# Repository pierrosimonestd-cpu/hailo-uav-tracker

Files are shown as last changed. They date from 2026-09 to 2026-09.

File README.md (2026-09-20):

# hailo-uav-tracker

**Real-time UAV detection and pan/tilt tracking on a Raspberry Pi 5 with a 13 TOPS Hailo-8L NPU.**





A camera on a two-axis turret finds a drone in the sky, decides which one to
follow, and keeps it centred while it moves. Detection runs on the NPU; the
tracker and a latency-compensating controller run on the Pi's CPU; an ESP32
drives the servos and holds a failsafe that does not depend on the Pi being
alive.

Accuracy is reported on the public [DUT Anti-UAV](https://github.com/wangdongdut/DUT-Anti-UAV)
benchmark (IEEE T-ITS 2022) under the COCO protocol. Pointing performance is
reported from a closed-loop simulation, clearly labelled as such. Every number
in this repository is produced by a script in `benchmarks/` and written to a
JSON file you can inspect.

---

## What is interesting here

Most edge-vision projects stop at "the model runs at N FPS". The question this
one is built around is different:

> **What does inference latency cost you in degrees of pointing error?**

It turns out that is the *only* question that matters for a tracking turret, and
it has a clean answer. Inference time enters the control loop as dead time. Dead
time caps the achievable loop bandwidth at roughly

$$\omega_c \approx \frac{0.8}{T_d + \tau}$$

which for this hardware is under 1 Hz — while the servos themselves could slew at
600 °/s. **The loop is latency-limited, not actuator-limited.** That is what the
accelerator buys, and it is measured on the real board: 153.6 ms of inference on
the Pi's CPU becomes 13.6 ms on the Hailo-8L, and steady-state pointing error
falls from 1.41° to 0.65°.

<!-- BEGIN GENERATED: readme-latency -->
| Sense-to-act latency | RMS pointing error |  |
| --- | --- | --- |
| 10 ms | **0.68°** | an accelerator with headroom to spare |
| 45 ms | **0.83°** | the budget `configs/rpi5_hailo8l.yaml` assumes |
| 120 ms | **1.21°** | a pipeline four times slower |
| 300 ms | **2.77°** | a pipeline near the edge of usable |
<!-- END GENERATED: readme-latency -->

Along the way, three things turned out to be more subtle than expected, and each
is written up with the wrong answers included:

- **Velocity feed-forward has two plausible formulations, and both are unstable.**
  Reconstructing the target's absolute rate from "apparent rate plus my own rate"
  is positive feedback with loop gain equal to the feed-forward gain.
  Reconstructing it from the commanded *angle* looks safe but puts a positive
  real pole at `1/τ_servo` into the loop. What works is reconstructing through a
  forward model of the actuator. [Write-up →](docs/control-design.md#5-velocity-feed-forward-and-two-ways-to-get-it-wrong)
- **The aim-time lead is the actuator's lag, not another detection latency.**
  Getting this wrong is invisible: it is correct at one particular frame rate.
  It produced a spurious minimum in the latency curve that looked like a real
  result. [Write-up →](docs/control-design.md#6-aim-time-a-subtle-but-expensive-detail)
- **The obvious serial protocol fails silently and permanently.** Two raw bytes
  per command means one dropped byte swaps pan and tilt for as long as the link
  stays up, and neither end can tell. [Write-up →](docs/hardware.md#why-not-two-raw-bytes)

---

## Results

### Detection — DUT Anti-UAV test split, COCO protocol

<!-- BEGIN GENERATED: detection -->
| Model | Backend | AP | AP50 | AP75 | AP_S | AP_M | AP_L | Images |
| ---: | ---: | ---: | ---: | ---: | ---: | ---: | ---: | ---: |
| `yolov8n-fp32-onnx` | onnx:cpu | 0.556 | 0.894 | 0.585 | 0.418 | 0.578 | 0.717 | 2200 |
| `yolov8n-fp32-pytorch` | ultralytics:cpu | 0.543 | 0.886 | 0.574 | 0.395 | 0.567 | 0.713 | 2200 |
| `yolov8n-int8-onnx` | onnx:cpu | 0.518 | 0.875 | 0.522 | 0.358 | 0.536 | 0.709 | 2200 |
| `yolov8n-negatives` | ultralytics:cpu | 0.503 | 0.865 | 0.514 | 0.356 | 0.559 | 0.657 | 2200 |
<!-- END GENERATED: detection -->

Read `AP_S` first: **52% of the objects in this dataset are smaller than 32×32
pixels**, and the median object covers under one tenth of one percent of the
frame. An aggregate AP can look respectable while the model has stopped seeing
distant targets, which are the ones worth detecting early.

### Latency

<!-- BEGIN GENERATED: latency -->
| Model | Host | Backend | Inference (ms) | End to end (ms) | p95 | p99 | FPS |
| ---: | ---: | ---: | ---: | ---: | ---: | ---: | ---: |
| `yolov8n-fp32-onnx-rpi5cpu` | Pi 5 CPU | onnx:cpu | 153.6 | 153.9 | 180.9 | 183.0 | 6.5 |
| `yolov8n-int8-onnx-rpi5cpu` | Pi 5 CPU | onnx:cpu | 75.0 | 75.3 | 93.6 | 96.0 | 13.3 |
| `yolov8n-fp32-onnx` | x86 desktop | onnx:cpu | 39.8 | 40.1 | 45.2 | 50.4 | 24.9 |
| `yolov8s-int8-hailo8l` | Pi 5 + Hailo-8L | hailo8l | 19.9 | 20.2 | 22.8 | 23.0 | 49.5 |
| `yolov8n-int8-hailo8l` | Pi 5 + Hailo-8L | hailo8l | 13.6 | 13.8 | 14.0 | 14.2 | 72.7 |
<!-- END GENERATED: latency -->

### Tracking — DUT Anti-UAV sequences

<!-- BEGIN GENERATED: tracking -->
| Model | Sequences | Frames | Success AUC | Success@0.5 | P@20px | Recall | Re-acquisitions |
| ---: | ---: | ---: | ---: | ---: | ---: | ---: | ---: |
| `yolov8n-fp32-pytorch` | 20 | 24,804 | 0.593 | 0.748 | 0.790 | 0.816 | 193 |
<!-- END GENERATED: tracking -->

Detect-and-track with no ground-truth initialisation, so this is a strictly
harder task than the single-object-tracking baselines published with the
dataset and is not compared against them. *Recall* keeps the rest honest: a
tracker can post a good success curve while answering on a third of the frames.

### Bird discrimination — the weakest result, and what fixing it costs

DUT Anti-UAV contains no birds, so a model trained on it alone has never been
told that a bird is not a drone. Measured against 593 bird photographs from
Open Images V7, with aircraft classes excluded:

<!-- BEGIN GENERATED: hard-negatives -->
| Model | Bird images | Threshold | False-positive rate | Threshold for 1% |
| ---: | ---: | ---: | ---: | ---: |
| `yolov8n-fp32-pytorch` | 593 | 0.35 | 23.44% | 0.9 |
| `yolov8n-negatives` | 593 | 0.35 | 7.08% | 0.7 |
<!-- END GENERATED: hard-negatives -->

**Close to one bird image in four triggers a UAV detection** on the baseline
model, which has never been shown a bird and told it is not a drone. Adding 600
bird photographs to training as background images and fine-tuning for four
epochs takes that to 7%.

That second number means nothing on its own — raising the confidence threshold
suppresses birds too, for free. And the fine-tuned model is *behind* on the
drone benchmark: AP 0.543 to 0.503. The obvious reading is that it just became
timid.

It did not. Compared at matched bird false-positive rates, it finds
substantially more drones at every operating point:

<!-- BEGIN GENERATED: negatives-tradeoff -->
| Target bird FP | Baseline thr / actual | Recall | With negatives thr / actual | Recall | &Delta; |
| ---: | ---: | ---: | ---: | ---: | ---: |
| 10.0% | 0.60 / 9.9% | 0.713 | 0.25 / 9.6% | **0.821** | +15% |
| 6.0% | 0.70 / 5.7% | 0.600 | 0.40 / 5.2% | **0.783** | +31% |
| 3.5% | 0.80 / 2.2% | 0.360 | 0.60 / 2.0% | **0.661** | +83% |
| 2.0% | 0.90 / 0.2% | 0.033 | 0.70 / 0.8% | **0.485** | +1392% &dagger; |

&dagger; the two models' actual bird rates differ by more than 1.5x here, so this row is not a matched comparison and its relative gain is overstated.
<!-- END GENERATED: negatives-tradeoff -->

The baseline needs confidence 0.70 to get birds to 5.7%, and there it has lost
40% of the drones. The fine-tuned model reaches a lower bird rate at 0.40, where
it still sees 78%. Its AP is lower because AP integrates the whole
precision-recall curve including the low-confidence tail no turret operates in —
the right summary for a detector in general, the wrong one for this decision.

Both checkpoints are kept, because which to deploy depends on whether false
alarms or missed drones cost more, and that is not a benchmark question.
[Method, caveats and the disjoint-split check](docs/benchmarks.md#fixing-it-birds-as-training-background).

### Predictions

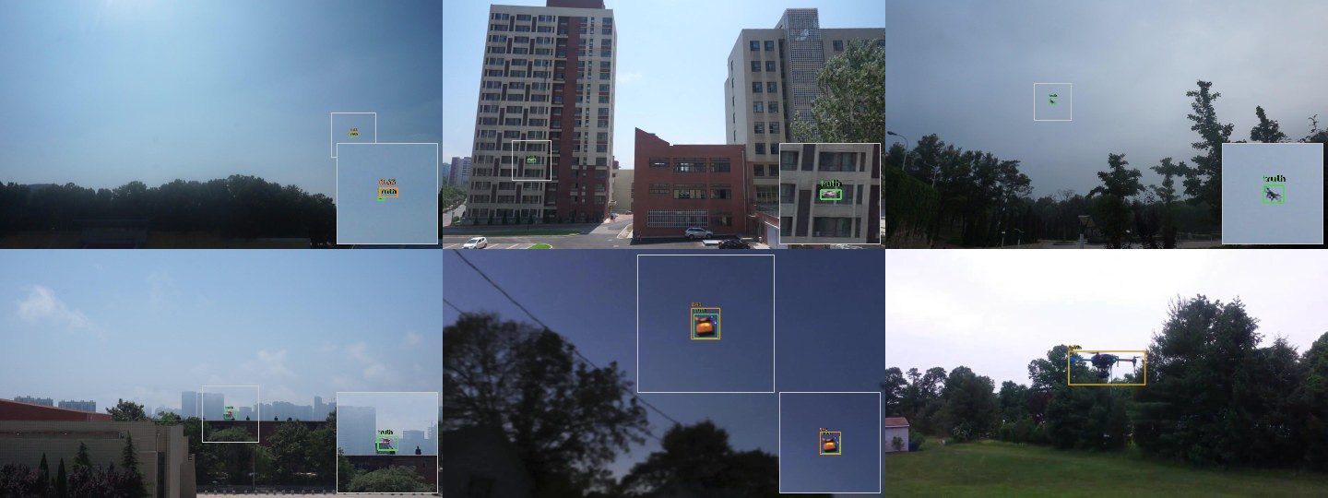
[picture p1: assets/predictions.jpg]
Predictions against ground truth


Six test images spanning the object-size range, smallest first. Green is ground
truth, orange is the model. Where the target is too small to see at this scale
the outlined region is magnified into the corner — which is itself the point:
most of this benchmark looks like the top-left cell, not the bottom-right one.

### Velocity feed-forward — closed-loop simulation

<!-- BEGIN GENERATED: readme-feedforward -->
| Target angular rate | PID only | PID + feed-forward |  |
| ---: | ---: | ---: | ---: |
| 4.7 °/s | 1.02° | **0.34°** | 67% lower |
| 14.1 °/s | 2.89° | **0.83°** | 71% lower |
| 28.3 °/s | 5.48° | **2.86°** | 48% lower |
<!-- END GENERATED: readme-feedforward -->

Full tables, methodology and the reproduction commands: **[docs/benchmarks.md](docs/benchmarks.md)**

---

## Quick start

### On a laptop, no hardware needed

```bash
git clone https://github.com/pierrosimonestd-cpu/hailo-uav-tracker
cd hailo-uav-tracker
pip install -e ".[dev,onnx,bench]"

pytest tests                                    # the whole library, no NPU required
python benchmarks/bench_control.py --study all  # reproduce the pointing tables
uavtrack simulate --trajectory crossing --latency-ms 45
```

### On the Raspberry Pi

```bash
sudo apt install -y hailo-all python3-picamera2
pip install -e .                                # NumPy, OpenCV, PyYAML, pyserial

uavtrack check --config configs/rpi5_hailo8l.yaml
uavtrack run   --config configs/rpi5_hailo8l.yaml --display
```

Full deployment guide, including compiling the model:
**[docs/hailo-deployment.md](docs/hailo-deployment.md)**

### Train your own detector

```bash
python tools/fetch_dut_antiuav.py --out data/dut_antiuav   # 10,000 annotated images
python tools/prepare_dataset.py   --root data/dut_antiuav  # VOC → YOLO + COCO
python tools/train_uav.py --epochs 20 --cache ram
python tools/export_onnx.py --weights runs/train/uav_yolov8n/weights/best.pt
bash tools/compile_hailo.sh models/uav_yolov8n_640.onnx    # needs the Hailo DFC
```

---

## How it works

```
┌────────────┐   BGR frame    ┌──────────────┐   detections   ┌─────────────┐
│  Camera    │───────────────▶│   Detector   │───────────────▶│   Tracker   │
│ Picamera2  │  1280×720@30   │  Hailo-8L    │  boxes+scores  │  ByteTrack  │
└────────────┘                │  YOLOv8n     │                │  + Kalman   │
      ▲                       └──────────────┘                └─────────────┘
      │                                                              │
      │ camera is rigidly mounted on the turret                      │
      │                                                              ▼
┌────────────┐   pan/tilt    ┌──────────────┐   target px    ┌─────────────┐
│  Servos    │◀──────────────│  ESP32       │◀───────────────│  Controller │
│  MG90S ×2  │     PWM       │ framed UART  │  pan/tilt deg  │  PID + FF   │
└────────────┘               └──────────────┘                └─────────────┘
```

| Stage | Runs on | Why |
|---|---|---|
| Detection + NMS | **Hailo-8L NPU** | 13 TOPS; NMS is compiled into the HEF so the CPU never sees raw head tensors |
| Tracking + control | Pi 5 CPU | Microseconds, NumPy only |
| Servo drive + failsafe | ESP32 | Hard-real-time PWM, and a failsafe independent of the Pi |

**Design notes worth reading:** [architecture.md](docs/architecture.md) ·
[control-design.md](docs/control-design.md) · [hardware.md](docs/hardware.md) ·
[dataset.md](docs/dataset.md)

### A few decisions and their reasons

**The Raspberry Pi install has no PyTorch.** Runtime dependencies are NumPy,
OpenCV, PyYAML and pyserial. The YOLO decode path is written in NumPy for this
reason. Training and benchmarking live in optional extras.

**One `Detection` type, three backends.** Hailo, ONNX Runtime and PyTorch all
return identical objects in original-frame pixels. The accuracy benchmark runs
the *same code path* the live pipeline runs, so it measures the system rather
than a benchmark-only wrapper — and the tests run on machines with no NPU.

**Timestamps come from capture, not from a nominal frame rate.** Inference time
on a shared NPU varies; a loop that assumes fixed `dt` accumulates a timing error
the Kalman filter cannot see.

**The failsafe is in the firmware.** If the Pi crashes, Python cannot clean up —
that is what crashing means. The ESP32 cuts the effector and detaches the servos
after 500 ms of silence, and the Pi sends heartbeats so silence is always
deliberate.

**Config typos are fatal.** `conf_treshold: 0.5` raises at startup instead of
being silently ignored.

---

## Repository layout

```
src/uavtrack/      detect/ · track/ · control/ · io/ · data/   the library
firmware/          ESP32 pan/tilt controller, framed protocol
hardware/cad/      printable STL/3MF plus Creo sources
benchmarks/        detection, tracking, latency, hard negatives, control
tools/             dataset fetch/prepare, train, export, quantise, Hailo compile
configs/           Pi + Hailo, and a desktop ONNX config
docs/              architecture, control design, benchmarks, hardware, dataset
tests/             274 tests, plus a C++ conformance test for the firmware
```

## Testing

```bash
pytest tests                       # runs anywhere; no NPU, no PyTorch, no turret
```

274 tests, 86% line coverage. The uncovered remainder is almost entirely the
three device-backed detection backends — Hailo needs an NPU, Ultralytics needs
PyTorch and a checkpoint — which is why everything downstream of them is written
against one `Detection` type that a stub can produce.

Some of those tests exist to keep the documentation honest rather than the code
correct: one re-derives every figure quoted in
[control-design.md](docs/control-design.md) from the measured JSON, another
fails on a broken link or a referenced script that does not exist, and a third
imports the whole library in a subprocess with PyTorch, ONNX Runtime, HailoRT
and SciPy blocked, so the claim about the Raspberry Pi install is enforced
rather than asserted.

CI additionally compiles the **actual firmware header** with a host C++ compiler
and runs the same protocol vectors and adversarial byte streams against it, so
the ESP32 and Python implementations cannot drift apart silently. It also builds
the firmware with `arduino-cli`, and fails if `docs/benchmarks.md` no longer
matches the JSON files in `benchmarks/results/`.

The tests that earn their keep are the ones pinning down specific failures: a
byte dropped on the serial link, a frame missed by the detector, an integrator
charging against a travel limit. Two real bugs found this way are documented in
[control-design.md](docs/control-design.md) §6 and [dataset.md](docs/dataset.md).

## What this does not do

Stated plainly, because a project's honesty is in what it admits rather than
what it claims.

**The accelerator numbers are not this project's detector.** The Hailo-8L
latency in the table above is measured — on a real Pi 5 with the AI HAT+,
`hailortcli` reporting `Device Architecture: HAILO8L`, firmware 4.23.0, through
this repository's own `HailoDetector` — but the compiled model is Hailo's
**COCO-trained yolov8n** from their Model Zoo, not the UAV detector trained
here. Compiling a `.hef` needs the Hailo Dataflow Compiler, which is x86_64
Linux only and behind a Developer Zone account, so the UAV weights have not
been through it.

The consequence is exact: the **latency is representative** — same
architecture, same 640×640 input, same device, same board — and **no detection
accuracy in this README was measured on the accelerator**. Run
`tools/compile_hailo.sh` on an x86 Linux box, copy the HEF to the Pi, and
`benchmarks/bench_latency.py` plus `benchmarks/eval_detection.py` will fill in
the rows that are still missing.

**The pointing results are simulation.** A rate-limited servo model with
transport delay, documented in [`plant.py`](src/uavtrack/control/plant.py). It
does not model backlash, stiction, boresight misalignment or a flexing 3D-printed
yoke — [control-design.md](docs/control-design.md) §9 lists the omissions. It is
how you decide what to take to the hardware, not a substitute for doing so.

**The INT8 study is a proxy.** ONNX Runtime static quantisation shares the
mechanisms that matter with the Hailo quantiser, but it is not that quantiser.

**Bird discrimination is improved, not solved.** The fine-tuned checkpoint still
fires on 7% of bird images, and the training and evaluation negatives are both
Open Images photographs — perched birds, close-ups, birds indoors — not birds in
flight against sky at range, which is the case that matters. The measurement is
a proxy, better than none and not the real thing. Four CPU epochs is also a small
budget for 600 new images; training with them included from the start would
likely beat both checkpoints rather than trading against one.

**The resize-kernel gain does not apply to the shipped configuration.** The
`INTER_AREA` preprocessing is worth about two points of `AP_small` on the
benchmark, but all of that comes from its 1920×1080 images. At the 1280×720 the
Pi config captures, the downscale to 640 is exactly 2:1, where OpenCV's bilinear
filter matches area-averaging to within one intensity level and the gain is
zero. Capturing
at 1080p might recover it; that has not been measured on hardware.
[Details](docs/benchmarks.md#the-resize-kernel-and-a-correctness-proof).

**Monocular, so no range.** Everything is angular. Two targets on the same
bearing at different distances are indistinguishable, which is simply true of
one camera.

**One target at a time.** The tracker follows several; the turret points at one,
chosen with hysteresis and a dwell time. No multi-target scheduling.

**Visible light only.** No thermal channel, so no night capability and a hard
time against a bright overcast sky.

**The servo model is unidentified.** `tau_s` and `delay_s` in
[`plant.py`](src/uavtrack/control/plant.py) are placeholders; the slew rate is
the MG90S datasheet figure. Until you identify your own, keep
`feedforward_gain` at 0.9 rather than 1.0 — the feed-forward is only as good as
that model.

## Credits and licence

MIT, see [LICENSE](LICENSE).

- **DUT Anti-UAV** — Zhao, Zhang, Li, Wang, *Vision-based Anti-UAV Detection and
  Tracking*, IEEE T-ITS 2022. [Dataset](https://github.com/wangdongdut/DUT-Anti-UAV)
- **ByteTrack** — Zhang et al., ECCV 2022,
  [arXiv:2110.06864](https://arxiv.org/abs/2110.06864). The association strategy;
  this is an independent implementation, not a port.
- **Ultralytics YOLOv8** — training and export.
- **Hailo** — HailoRT, the Dataflow Compiler and the published Model Zoo figures
  quoted in [benchmarks.md](docs/benchmarks.md) §4.
- **Open Images V7** — bird images for the hard-negative benchmark.

Hailo throughput figures quoted in this repository are Hailo's own published
COCO measurements on an Intel host, attributed as such, and are not measurements
from this project.

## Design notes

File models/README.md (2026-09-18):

# Model artifacts

This directory is where the build products land. None of them are committed —
they are derived files, and a repository that carries 25 MB of weights per
experiment stops being clonable.

| File | Produced by | Used by |
|---|---|---|
| `uav_yolov8n_640.onnx` | `tools/export_onnx.py` | ONNX Runtime backend; input to the Hailo compiler |
| `uav_yolov8n_640.int8.onnx` | `tools/quantize_onnx.py` | The INT8 accuracy study |
| `calibration.npy` | `tools/make_calibration_set.py` | The Hailo optimiser |
| `uav_yolov8n_640.har` | `tools/compile_hailo.sh` (parse step) | Intermediate; inspect with `hailo profiler` |
| `uav_yolov8n_640.hef` | `tools/compile_hailo.sh` (compile step) | What actually runs on the Pi |

## Getting a model

Train one:

```bash
python tools/fetch_dut_antiuav.py --out data/dut_antiuav
python tools/prepare_dataset.py   --root data/dut_antiuav
python tools/train_uav.py --epochs 20 --cache ram
python tools/export_onnx.py --weights runs/train/uav_yolov8n/weights/best.pt
```

Then, on an x86_64 machine with the Hailo Dataflow Compiler:

```bash
python tools/make_calibration_set.py --out models/calibration.npy
bash tools/compile_hailo.sh models/uav_yolov8n_640.onnx models/calibration.npy
```

See [docs/hailo-deployment.md](../docs/hailo-deployment.md) for the parts of
that flow that will bite you.

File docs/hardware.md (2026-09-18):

# Hardware

A two-axis pan/tilt turret carrying a camera, driven by an ESP32, commanded by a
Raspberry Pi 5 with a Hailo-8L NPU.

## Bill of materials

| Part | Notes |
|---|---|
| Raspberry Pi 5, 4 GB or 8 GB | 8 GB only helps if you also train on it, which you should not |
| Raspberry Pi AI HAT+ 13 TOPS (Hailo-8L) | The 26 TOPS Hailo-8 variant works unchanged; set `HW_ARCH=hailo8` when compiling |
| Raspberry Pi Camera Module 3 | 66° horizontal FOV. Any camera works — **measure the FOV** |
| ESP32 devkit (e.g. DOIT DevKit v1) | Any ESP32 with USB serial |
| 2 × MG90S metal-gear servo | Plastic-gear SG90s strip under the side loads from a camera mount |
| 5 V 2 A+ supply for the servos | **Separate from the Pi.** See below |
| Logic-level MOSFET module or 3.3 V relay | Drives the effector output |
| 608ZZ bearing | Takes the radial load off the pan servo's output shaft |
| M3 hardware, USB-C cable | |

Printed parts are in [`../hardware/cad`](../hardware/cad) — STL and 3MF for
printing, Creo sources under `creo/`.

| File | Part |
|---|---|
| `base_plate.stl` | Fixed base, pan servo mount |
| `base_rpi5_tray.stl` | Pi 5 + AI HAT+ tray |
| `yoke_pan.stl` | Rotating yoke |
| `tilt_arm.stl` | Tilt arm |
| `camera_mount_v2.stl` | Camera mount (v2; v1 kept for reference) |
| `bearing_holder.stl` | 608ZZ seat |
| `yoke_mg90s_fit_test.stl` | Print this first — checks the servo pocket fit |

Print `yoke_mg90s_fit_test.stl` before committing to a four-hour print. Servo
body tolerances vary between suppliers, and a pocket 0.3 mm undersized means
either a broken part or a servo you cannot remove.

The Creo sources under `hardware/cad/creo/` keep the native `.prt.N` versioning,
where the **highest** `N` is the current revision -- `base.prt.6` supersedes
`base.prt.5`. Earlier revisions are kept because they are the design history;
only the STL and 3MF exports are what you print.

The part names are Italian, because that is what they were modelled as, and
renaming a Creo part breaks retrieval by name. So they are translated rather
than renamed:

| Creo part | Literally |
|---|---|
| `base.prt` | "base" |
| `base_rpi.prt` | "Raspberry Pi base" |
| `u_torretta.prt` | "turret" |
| `attacco_camera.prt` | "camera attachment" |
| `attacco_cuscinetto_rivisto.prt` | "revised bearing seat" |
| `prt0001.prt`, `prt0002.prt` | nothing -- Creo's default name for a part nobody renamed |

Which STL each one exports to was never recorded, so it is not claimed here.
Open the part if you need to know; the printable geometry is the STL either way.

## Power — read this part

**Do not power the servos from the Pi or from the ESP32.** MG90S stall current
is around 700 mA each, with startup transients well above that. An ESP32's
regulator supplies a few hundred milliamps, so the board browns out and resets
the instant both servos move together. The symptom is a turret that works
perfectly until it has to track something.

```
5 V 2 A+ supply ──┬── servo V+ (red)
                  └── (do NOT connect to the ESP32 5 V pin)

        GND ──────┬── servo GND (brown/black)
                  ├── ESP32 GND
                  └── MOSFET / relay module GND        ← all grounds common
```

The common ground is not optional. Without it the PWM signal has no reference
and the servos jitter or ignore commands entirely.

A 470–1000 µF electrolytic across the servo supply, physically close to the
servos, absorbs the switching transients. Cheap, and it removes a whole class of
intermittent faults.

## Wiring

| Signal | ESP32 pin | Goes to |
|---|---|---|
| Pan servo PWM | GPIO 13 | Servo signal (orange/yellow) |
| Tilt servo PWM | GPIO 12 | Servo signal |
| Effector | GPIO 21 | MOSFET gate or relay input |
| Serial | USB-C | Raspberry Pi USB port |

Pin assignments are at the top of
[`esp32_pantilt.ino`](../firmware/esp32_pantilt/esp32_pantilt.ino).

The effector pin **cannot drive a load directly** — an ESP32 GPIO supplies 3.3 V
at a few tens of milliamps. Use a logic-level MOSFET (IRLZ44N or similar) or a
relay module rated for 3.3 V logic.

### Servo pulse range

The firmware attaches the servos with a 500–2400 µs pulse range rather than the
1000–2000 µs Arduino default. MG90S servos use the wider range; clipping it
throws away roughly a third of the mechanical travel, which shows up as a turret
that mysteriously cannot reach the edges of its own field of regard.

## Mechanical limits

Configured in both `configs/rpi5_hailo8l.yaml` and the firmware, deliberately:

| Axis | Range | Why |
|---|---|---|
| Pan | 0–180° | Full servo travel |
| Tilt | 20–160° | The camera mount fouls the base below 20° |

**Check these against your own build before powering on.** Both ends enforce
them so a bug on the Pi cannot drive the mechanism into itself, but neither end
knows your print tolerances.

## Firmware

```bash
arduino-cli config init
arduino-cli config set board_manager.additional_urls \
  https://raw.githubusercontent.com/espressif/arduino-esp32/gh-pages/package_esp32_index.json
arduino-cli core update-index
arduino-cli core install esp32:esp32
arduino-cli lib install ESP32Servo

arduino-cli compile --fqbn esp32:esp32:esp32doit-devkit-v1 firmware/esp32_pantilt
arduino-cli upload -p /dev/ttyUSB0 --fqbn esp32:esp32:esp32doit-devkit-v1 firmware/esp32_pantilt
```

If upload fails at `Connecting...`, hold the BOOT button until it starts.

### What the firmware guarantees

The Pi does the thinking; the firmware's entire job is to be the part that stays
safe when the thinking stops.

- **Failsafe.** No valid frame for 500 ms and the effector is cut and the servos
  are *detached* — PWM stops, so they go limp rather than straining against
  whatever they are pressed into. The Pi sends heartbeats to prove it is alive,
  so silence is always deliberate.
- **Starts inert.** The turret does not move on power-up until the host has
  spoken to it. A power cycle cannot make it move on its own.
- **Framed commands.** Sync word, length, CRC-8. A corrupt frame is counted and
  dropped, never acted on.
- **Independent rate limiting.** Commands are slew-limited in the firmware as
  well as on the Pi, so a bad command cannot ask for a step big enough to brown
  out the supply.
- **Telemetry.** A `STATUS` frame every 200 ms reporting the last sequence
  number, dropped frames and CRC errors — so link quality is observable rather
  than guessed at.

### Why not two raw bytes

The obvious protocol is to write pan and tilt as two bytes and have the firmware
read them whenever two are available. It has a failure mode that is silent and
permanent: drop one byte anywhere and every subsequent pair is read off by one,
so pan is interpreted as tilt for as long as the link stays up. Neither end can
tell.

Measured on the framed protocol with 1% of bytes randomly dropped: **173 of 200
frames recovered, and zero frames delivered with wrong content**
(`tests/test_protocol.py`). Frames are lost, never misread. That is the property
worth having, and it costs seven bytes of overhead per command.

The full frame layout is in
[`protocol.py`](../src/uavtrack/io/protocol.py), and
[`protocol.h`](../firmware/esp32_pantilt/protocol.h) must stay byte-identical —
`tests/test_protocol.py` pins the CRC vectors both sides have to reproduce.

## Assembly notes

1. Print and test-fit `yoke_mg90s_fit_test.stl` first.
2. Centre both servos at 90° **before** attaching the horns, or the mechanical
   range will be offset from the commanded range and the limits will be wrong.
3. Seat the 608ZZ bearing in `bearing_holder.stl` — it carries the radial load
   the pan servo's output shaft should not.
4. Route the camera ribbon with slack through the full pan range. It is the
   first thing to fail.
5. Power the servo supply and the Pi separately; join grounds.
6. Upload the firmware and verify with `uavtrack check` before mounting the
   camera.

## Calibrating the field of view

`horizontal_fov_deg` sets the pixel-to-angle gain for the whole control loop.
Getting it wrong is indistinguishable from mistuning every gain at once.

Measure it: place a target of known width `W` at a known distance `D`,
perpendicular to the optical axis, and note the pixel width `p` it occupies in a
full-frame capture.

$$\text{HFOV} = 2\arctan\left(\frac{W_\text{frame}}{2D}\right), \qquad W_\text{frame} = W\cdot\frac{W_\text{image px}}{p}$$

Put the result in your config. Do not trust the marketing figure — it is quoted
for the full sensor, and most capture modes crop.

---

**See also:** [control-design.md](control-design.md) ·
[hailo-deployment.md](hailo-deployment.md)

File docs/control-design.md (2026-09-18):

# Control design

How the turret decides where to point, why it is built this way, and what each
decision is worth in measured degrees.

Everything here is reproducible with:

```bash
python benchmarks/bench_control.py --study all
```

Results are written to `benchmarks/results/control_simulation.json`. They are
**simulation** results — the servo model is described below and in
[`plant.py`](../src/uavtrack/control/plant.py). They are not a substitute for
measuring on your own hardware, they are how you decide what is worth measuring.

---

## 1. The loop

```
frame ──▶ detector ──▶ tracker ──▶ selector ──▶ controller ──▶ serial ──▶ servos
  ▲                                                                          │
  └──────────────────── camera is bolted to the turret ──────────────────────┘
```

The feedback path is mechanical: the camera moves with the turret, so a pixel
measurement is an angle *relative to wherever the turret currently points*. That
single fact drives most of the design.

## 2. Pixels to angles

A pixel offset is not proportional to an angle. Through a pinhole model:

$$\theta = \arctan\left(\frac{\Delta x}{f}\right), \qquad f = \frac{W/2}{\tan(\text{HFOV}/2)}$$

Using the small-angle approximation $\theta \approx \Delta x / f$ instead makes
the effective loop gain fall off towards the frame edges — a controller tuned on
a centred target goes sluggish exactly when the target is about to leave frame.
At the edge of a 66° lens the approximation is off by about 10%.

The lens field of view therefore sets the loop gain. **Measure it.** Getting
`horizontal_fov_deg` wrong is indistinguishable from mistuning every gain.

## 3. Why the loop is latency-limited, not actuator-limited

The MG90S servos slew at 600 °/s. The loop cannot use anything close to that.

The plant seen by the controller is an integrator (commanded rate integrates to
angle) behind a dead time $T_d$ and a lag $\tau$. For a 45° phase margin the
crossover $\omega_c$ must satisfy

$$\omega_c T_d + \arctan(\omega_c \tau) = 45° $$

With $T_d \approx 65$ ms (detection latency plus serial and servo transport) and
$\tau \approx 80$ ms, that gives $\omega_c \approx 5.6$ rad/s — under 1 Hz — and
a proportional gain of roughly

$$k_p = \omega_c\sqrt{1 + (\tau\omega_c)^2} \approx 6$$

So $k_p$ is capped near 6 by *latency*, while the actuator could support far
more. This is the single most important fact about the system, and it is the
reason an NPU matters: **inference time is loop dead time.**

Measured, by sweeping the sense-to-act latency and tracking a target orbiting at
14 °/s (mean of five seeds, steady state after 2 s):

| Sense-to-act latency | RMS pointing error |
|---:|---:|
| 10 ms | 0.68° |
| 20 ms | 0.69° |
| 30 ms | 0.73° |
| 45 ms | 0.83° |
| 60 ms | 0.87° |
| 80 ms | 1.01° |
| 120 ms | 1.21° |
| 160 ms | 1.45° |
| 200 ms | 1.83° |
| 300 ms | 2.77° |

Pointing error grows roughly four-fold from 10 ms to 300 ms. Latency is the
budget the whole perception stack spends from.

## 4. The PID, and the three ways the textbook version fails

[`pid.py`](../src/uavtrack/control/pid.py) is a PID with three modifications,
each fixing a failure with a visible symptom on a turret:

| Problem | Symptom | Fix |
|---|---|---|
| Integral windup | Long overshoot after the target returns from beyond a travel limit | Back-calculation: unwind the integrator by exactly what the actuator refused to deliver |
| Derivative kick | Violent jerk each time the selector switches target | Differentiate the *measurement*, not the error |
| Derivative noise | Servo buzz tracking box jitter | First-order low-pass at 8 Hz on the derivative term |

Anti-windup is worth measuring rather than asserting. Driving an integrator
plant to a distant setpoint through a saturating actuator
(`tests/test_control.py::test_anti_windup_reduces_overshoot_after_saturation`),
back-calculation cuts overshoot by more than 4×.

Tuned gains, from the sweep in `benchmarks/bench_control.py`:

```
kp = 4.5    ki = 0.5    kd = 0.25
```

`kp` sits below the stability-limited ≈6 for margin against an unidentified
servo. `ki` is small: it exists to remove static bias, not to chase motion —
that is the feed-forward's job.

## 5. Velocity feed-forward, and two ways to get it wrong

A rate-commanded loop of this shape has a steady velocity-lag error of

$$e_{ss} = \frac{\dot\theta_{\text{target}}}{k_p}$$

At 14 °/s with $k_p = 4.5$ that is **3.1° of permanent lag**. Raising $k_p$ is
not available (§3), and integral action large enough to remove it destabilises
the loop. Feed-forward cancels it open-loop instead: add the target's angular
rate directly to the commanded rate.

That needs the target's rate in *world* coordinates, and the camera only
measures relative angles. Reconstructing it is where this gets interesting.

**Wrong approach 1 — add back your own commanded rate.** "Apparent rate plus my
own rate" seems to reconstruct the absolute rate. It is a positive feedback path
with loop gain equal to the feed-forward gain: the fixed point requires
$g_{ff} = 1$ exactly, and any bias is amplified by $1/(1-g_{ff})$. Measured
before it was removed: unstable within a second, RMS error rising from 3.6° to
over 90°.

**Wrong approach 2 — reconstruct from the commanded angle.** Safer-looking, and
still wrong. These servos have no encoder, so the commanded angle leads the real
one by the servo lag:

$$\hat\theta_{\text{target}} = \theta_{\text{cmd}} + \theta_{\text{offset}} = \theta_{\text{target}} + \tau_{\text{eff}}\,\dot\theta_{\text{cmd}}$$

Differentiating, $\dot\theta_{cmd} - \tau_{\text{eff}}\ddot\theta_{cmd} =
\dot\theta_{\text{target}}$ — a **positive real pole at $1/\tau_{\text{eff}}
\approx 12\ \text{s}^{-1}$**. It diverges in under a second. Measured: RMS error
of 88° at $g_{ff} = 0.9$.

**What works — reconstruct through a model of the servo.** The controller keeps
a forward model of its own actuator ([`ServoModel`](../src/uavtrack/control/plant.py))
and reconstructs the bearing against the *model's output* rather than against
the raw command. The lag term cancels, the feedback path disappears, and gains
near 1.0 are stable.

The reconstructed bearings then go into a
[`BearingEstimator`](../src/uavtrack/control/gimbal.py): a least-squares line fit
over a five-sample sliding window, fitted against *timestamps* rather than
sample indices so a dropped frame or a jittering inference time does not bias the
slope. The fit gives both the smoothed bearing and its rate, and extrapolating it
is what performs latency compensation.

Measured effect (steady state, five seeds, circular target):

| Peak target rate | FF off | FF on | Reduction |
|---:|---:|---:|---:|
| 4.7 °/s | 1.02° | 0.34° | 67% |
| 9.4 °/s | 1.93° | 0.41° | 79% |
| 14.1 °/s | 2.89° | 0.83° | 71% |
| 18.9 °/s | 3.81° | 1.36° | 64% |
| 28.3 °/s | 5.48° | 2.86° | 48% |

Feed-forward removes roughly two thirds of the pointing error on a moving
target. The benefit tapers at high rates, where the linear fit stops describing
the motion within its own window.

## 6. Aim time: a subtle but expensive detail

The command should aim at where the target will be when the turret *gets there*.
Measured from now, that is the **actuator's** lag — not another detection
latency. The detection latency is already accounted for by timestamping the
observation at capture time.

Getting this wrong is not obviously wrong: leading by `2 × latency` happens to be
correct at one particular frame rate. During development this produced a
spurious minimum in the latency sweep at 80 ms — the over-lead accidentally
cancelling the under-compensation — which looked like a real result until the
test on a constant-velocity target (where a linear extrapolator should be exact)
showed a residual that no amount of latency should cause. After the fix, error
on a constant-velocity target dropped from 1.18° to 0.11° at 10 ms latency, and
the latency sweep became monotonic.

The lesson generalises: if a performance curve has a minimum somewhere other
than the physical limit, look for two errors cancelling.

## 7. Robustness to dropped detections

The Kalman filter coasts a lost track on its velocity estimate, so missed
detections degrade gracefully rather than opening the loop:

| Detections missed | RMS error | Target in frame |
|---:|---:|---:|
| 0% | 0.83° | 100% |
| 10% | 0.84° | 100% |
| 20% | 0.84° | 100% |
| 30% | 0.85° | 100% |
| 50% | 1.07° | 100% |
| 70% | 48.1° | 78% |

Flat to 50%, then a cliff. The cliff is the `max_age` limit: past roughly half
the frames missing, gaps regularly exceed the coasting budget and the track is
dropped. If your detector misses more than half the frames, the answer is a
better detector, not a longer `max_age` — coasting for a second on a two-second-old
velocity estimate points at empty sky.

## 8. The servo model

```python
ServoModel(tau_s=0.08, max_rate_deg_s=600.0, delay_s=0.02)
```

Transport delay, then a first-order lag, then a hard slew-rate limit. The rate
limit is the dominant nonlinearity in a pan/tilt turret and the reason a
controller tuned purely against a linear model overshoots on real hardware:
during a large step the actuator is rate-limited, the loop is effectively open,
and any integrator keeps charging.

`max_rate_deg_s = 600` is the MG90S datasheet figure at 4.8 V (0.1 s per 60°).
`tau_s` and `delay_s` are **placeholders until identified on your hardware.**
Until you do, keep `feedforward_gain` at 0.9 rather than 1.0 — the feed-forward
is only as good as this model.

## 9. What is not modelled

Stated plainly, because a simulation's honesty is in its omissions:

- **Backlash and stiction.** Present in MG90S gear trains, and the reason for
  the deadband. Not modelled; expect a real limit cycle the simulation does not
  show.
- **Camera-to-turret misalignment.** Assumed zero. A real build has a boresight
  offset that shows as a constant pointing bias.
- **Lens distortion.** A pure pinhole model. Real wide lenses need calibration.
- **Structural flexibility.** The turret is rigid here. A 3D-printed yoke is not.
- **Target range.** Everything is angular. Two targets at the same bearing and
  different ranges are indistinguishable, which is exactly true of a monocular
  camera.

---

**See also:** [architecture.md](architecture.md) ·
[benchmarks.md](benchmarks.md) · [hardware.md](hardware.md)

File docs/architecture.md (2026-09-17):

# Architecture

## The loop, end to end

```
┌────────────┐   BGR frame    ┌──────────────┐   detections   ┌─────────────┐
│  Camera    │───────────────▶│   Detector   │───────────────▶│   Tracker   │
│ Picamera2  │  1280×720@30   │  Hailo-8L    │  boxes+scores  │  ByteTrack  │
└────────────┘                │  YOLOv8n     │                │  + Kalman   │
      ▲                       └──────────────┘                └─────────────┘
      │                                                              │
      │ camera is rigidly mounted on the turret                      │ tracks
      │                                                              ▼
┌────────────┐   pan/tilt    ┌──────────────┐   target px    ┌─────────────┐
│  Servos    │◀──────────────│  ESP32       │◀───────────────│  Controller │
│  MG90S ×2  │     PWM       │  framed UART │  pan/tilt deg  │ PID + FF    │
└────────────┘               └──────────────┘                └─────────────┘
                                                                     ▲
                                                             ┌─────────────┐
                                                             │  Selector   │
                                                             │  hysteresis │
                                                             └─────────────┘
```

Where the work happens:

| Stage | Runs on | Why there |
|---|---|---|
| Capture | Pi 5, libcamera | Direct to Picamera2, no V4L2 shim |
| Detection | **Hailo-8L NPU** | 13 TOPS; the Pi CPU cannot do this in real time |
| NMS | **Hailo-8L NPU** | Compiled into the HEF, so the CPU never sees raw head tensors |
| Tracking | Pi 5 CPU | Microseconds; NumPy only |
| Control | Pi 5 CPU | Microseconds |
| Servo drive | ESP32 | Hard-real-time PWM, and a failsafe independent of the Pi |

## Package layout

```
src/uavtrack/
├── detect/            Detection backends behind one interface
│   ├── base.py          Detection, DetectorBackend
│   ├── preprocess.py    Letterbox + its inverse
│   ├── postprocess.py   YOLO head decode + NMS, NumPy only
│   ├── hailo_backend.py HailoRT async API, on-chip NMS
│   ├── onnx_backend.py  ONNX Runtime (reference implementation)
│   ├── ultralytics_backend.py  PyTorch (training-time reference)
│   └── factory.py       Backend selection
├── track/             Multi-object tracking
│   ├── kalman.py        Constant-velocity filter, DWNA process noise
│   ├── bytetrack.py     Two-stage IoU association
│   └── selector.py      Primary-target policy with hysteresis
├── control/           Pointing
│   ├── pid.py           Anti-windup, derivative-on-measurement, filtered
│   ├── gimbal.py        Pixel→angle, bearing reconstruction, feed-forward
│   ├── plant.py         Servo model and generic discrete transfer functions
│   └── simulator.py     Closed-loop simulation
├── io/                The outside world
│   ├── camera.py        Picamera2 / OpenCV / image-sequence sources
│   ├── protocol.py      Framed wire protocol with CRC-8
│   └── serial_link.py   Transport, heartbeat, statistics
├── data/voc.py        VOC → YOLO and VOC → COCO conversion
├── config.py          Typed YAML config that rejects unknown keys
├── pipeline.py        Wires it all together
├── viz.py             Overlays
└── cli.py             `uavtrack run | check | simulate`
```

## Design decisions

### One `Detection` type, three backends

Every backend returns identical `Detection` objects in **original-frame pixel
coordinates**. Nothing downstream knows whether inference ran on a Hailo-8L, on
ONNX Runtime or on PyTorch. This is what makes the accuracy benchmarks
meaningful: `benchmarks/eval_detection.py` runs the same code path the live
pipeline runs, so it measures the system rather than a benchmark-only wrapper.

It is also what makes development possible at all — the NPU exists on exactly
one machine, and the tests need to run everywhere.

### The Raspberry Pi install has no PyTorch

Runtime dependencies are NumPy, OpenCV, PyYAML and pyserial. Training, export
and benchmarking dependencies are extras (`[train]`, `[onnx]`, `[bench]`). The
decode path in `postprocess.py` is NumPy for this reason.

### Timestamps come from capture, not from a nominal frame rate

Inference time on a shared NPU varies. A loop assuming a fixed `dt` accumulates
timing error the Kalman filter cannot see. Real elapsed times are threaded
through every stage, and `dt <= 0` is rejected rather than propagated.

### Failsafe lives in the firmware, not in Python

If the Pi crashes, the Python process cannot clean up — that is what crashing
means. The ESP32 trips its own failsafe after 500 ms of silence: effector cut,
servos detached. The Pi sends heartbeats to prove it is alive, so silence is
always deliberate.

### Config is a dataclass tree, and typos are fatal

`conf_treshold: 0.5` in a YAML dict would be silently ignored. Here it raises at
startup. On a system where a wrong gain means a turret hitting its end stop,
failing loudly at load time is the cheap option.

## Data flow per frame

1. **Capture** — `(monotonic_timestamp, bgr_frame)`. Timestamped at capture.
2. **Letterbox** — aspect-preserving resize to 640×640, centre-padded with 114.
   The `Letterbox` object carries its own inverse.
3. **Inference** — uint8 straight to the NPU; normalisation happens on chip.
4. **NMS** — on chip. Returns per-class `[y_min, x_min, y_max, x_max, score]`,
   normalised to the letterboxed input.
5. **Inverse transform** — back to original-frame pixels, clipped.
6. **Association** — two-stage IoU: confident detections first, then a rescue
   pass with weak ones. Kalman-predicted boxes are what is matched against.
7. **Selection** — score by confidence, apparent size and centrality, with an
   incumbent bonus and a dwell time so the turret cannot oscillate between
   targets.
8. **Control** — reconstruct absolute bearing through the servo model, fit a
   rate over a sliding window, extrapolate to the aim time, PID plus feed-forward.
9. **Command** — one framed, CRC-checked `SET_ANGLES`.

## Failure modes and what handles them

| Failure | Handled by |
|---|---|
| Detector misses frames | Kalman coasting; graceful to ~50% loss |
| Two UAVs in frame | Selector hysteresis and dwell time |
| Target occluded | Track kept `LOST` for `max_age` frames |
| Serial byte dropped | Sync word + CRC-8; frame dropped, never misread |
| Pi crashes or unplugged | ESP32 failsafe after 500 ms |
| Target beyond travel | Axis limits clamp; anti-windup prevents the overshoot on return |
| Target lost entirely | Controller integrators reset, so no stale error on re-acquisition |
| Bad config | Rejected at load |

---

**See also:** [control-design.md](control-design.md) ·
[hailo-deployment.md](hailo-deployment.md) · [hardware.md](hardware.md)

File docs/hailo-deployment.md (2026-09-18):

# Deploying to the Raspberry Pi AI HAT+ (Hailo-8L, 13 TOPS)

Two machines are involved, and confusing them wastes an afternoon:

| | Compile | Run |
|---|---|---|
| Machine | x86_64 Linux | Raspberry Pi 5 |
| Software | Hailo **Dataflow Compiler** (DFC) | **HailoRT** + `hailo_platform` |
| Input | `.onnx` | `.hef` |
| Output | `.hef` | detections |

The Pi does not compile. The DFC is distributed through the Hailo Developer Zone
and needs an account, which is why compilation is a script you run rather than a
CI job.

---

## 1. Hardware

- Raspberry Pi 5 (4 GB or 8 GB)
- Raspberry Pi **AI HAT+ 13 TOPS** (Hailo-8L). The 26 TOPS version carries a
  Hailo-8; set `HW_ARCH=hailo8` when compiling and everything else is identical.
- Raspberry Pi OS **Bookworm, 64-bit**

The HAT connects over PCIe Gen 3. Confirm Gen 3 is enabled — Gen 2 roughly halves
the achievable throughput:

```bash
grep -q "^dtparam=pciex1_gen=3" /boot/firmware/config.txt || \
  echo "dtparam=pciex1_gen=3" | sudo tee -a /boot/firmware/config.txt
sudo reboot
```

## 2. Runtime install on the Pi

One command does all of section 2 and checks its own work:

```bash
./tools/provision_pi.sh
```

It installs the packages below, builds the virtualenv correctly, installs the
project and then verifies the PCIe link, HailoRT, the Python bindings and the
camera -- reporting which of those failed rather than exiting on the first one.
Re-running it is safe. `./tools/provision_pi.sh --verify` checks without
changing anything.

The manual equivalent:

```bash
sudo apt update
sudo apt install -y hailo-all python3-picamera2 python3-opencv python3-venv
sudo reboot
```

`hailo-all` pulls in the PCIe driver, the firmware, HailoRT and the Python
bindings. Verify:

```bash
hailortcli fw-control identify
```

The output must name **HAILO8L** and report a firmware version. If the device is
not found, it is nearly always the PCIe link: check `dmesg | grep -i hailo`.

Then install this project:

```bash
git clone https://github.com/pierrosimonestd-cpu/hailo-uav-tracker
cd hailo-uav-tracker
python3 -m venv --system-site-packages .venv
source .venv/bin/activate
pip install -e .            # NumPy, OpenCV, PyYAML, pyserial. No PyTorch.
```

Both flags on that venv line are load-bearing:

- **`--system-site-packages`.** `hailo_platform` and `picamera2` are apt
  packages, not pip packages. A venv without this cannot see them, and the
  Hailo backend fails to import on a machine where the runtime is installed
  perfectly.
- **The venv itself.** Bookworm marks its system Python as externally managed
  (PEP 668), so `pip install -e .` outside a venv is refused. The venv is the
  fix; `--break-system-packages` is not -- it installs this project's
  dependencies over apt-managed ones and the next `apt upgrade` gets to
  arbitrate.

## 3. Compiling the model (on x86_64)

```bash
# 1. Train, or download a release checkpoint
python tools/train_uav.py --data data/dut_antiuav/dut_antiuav.yaml --epochs 20

# 2. Export to ONNX: opset 13, static shapes, no NMS
python tools/export_onnx.py --weights runs/train/uav_yolov8n/weights/best.pt

# 3. Build the calibration tensor from TRAINING images
python tools/make_calibration_set.py --out models/calibration.npy --count 1024

# 4. Parse, quantise, compile
bash tools/compile_hailo.sh models/uav_yolov8n_640.onnx models/calibration.npy
```

### Things that will bite you

**Opset.** The DFC parses opsets 11–13 reliably. `tools/export_onnx.py` pins
**13**, not 11: opset 11's `QuantizeLinear` has no `axis` attribute, so the INT8
study in [benchmarks.md](benchmarks.md) cannot use per-channel weights and fails
at load with `INVALID_GRAPH`. Opset 13 satisfies both the compiler and the
quantiser, so one export serves both paths.

**End node names.** The parser needs to be told where the graph ends, because
the NMS node is attached by the compiler rather than exported. The defaults in
`compile_hailo.sh` match a stock Ultralytics YOLOv8 export; confirm against your
own:

```bash
python -c "import onnx; m=onnx.load('models/uav_yolov8n_640.onnx'); print([n.name for n in m.graph.node][-12:])"
```

**The sigmoid on the classification branches.** Cutting the graph at the head
convolutions cuts *before* the activation, and the NMS node expects
probabilities. The layer names are assigned by the parser and differ per model,
so they are deliberately not hardcoded. List them from the parsed HAR and pass
them in:

```bash
hailo profiler models/uav_yolov8n_640.har | grep conv
CLS_OUTPUT_LAYERS="conv42,conv53,conv63" bash tools/compile_hailo.sh models/uav_yolov8n_640.onnx
```

Skip this and every score comes out as a logit, every detection is filtered out,
and the pipeline runs perfectly while detecting nothing.

**Calibration set.** Hailo recommends at least 1024 images, pre-processed
exactly as at inference. `make_calibration_set.py` reuses the pipeline's own
`letterbox()` for this reason, and draws from the **training** split —
calibrating on test images leaks the test set.

**Normalisation on chip.** The generated model script puts the `/255` on the
device, so the runtime feeds it uint8. That saves a float conversion and a 4×
larger PCIe transfer per frame. The `HailoDetector` matches this by setting
`FormatType.UINT8` on the input; changing one without the other silently
destroys accuracy.

## 4. Running

```bash
scp models/uav_yolov8n_640.hef pi@raspberrypi:~/hailo-uav-tracker/models/

# on the Pi
uavtrack check --config configs/rpi5_hailo8l.yaml
uavtrack run   --config configs/rpi5_hailo8l.yaml --display
```

`check` validates the config, resolves the backend and confirms the model file
exists — run it before wondering why nothing happens.

## 5. Measure your own latency

The single most important number in `configs/rpi5_hailo8l.yaml` is
`control.latency_s`. It is loop dead time, and [control-design.md](control-design.md)
shows what it costs. Measure it rather than trusting the default:

```bash
python benchmarks/bench_latency.py --model models/uav_yolov8n_640.hef --frames 300
```

Set `control.latency_s` from the median-to-p95 range. Quote the tail, not the
mean: one late frame in fifty hurts a pointing solution more than a mean that is
5 ms worse.

## 6. Published Hailo-8L throughput

For reference, from the Hailo Model Zoo — these are **Hailo's published figures
on COCO**, measured on an Intel Core i5-9400 over PCIe Gen 3 ×4 with Dataflow
Compiler v2.19.0. They are not measurements from this project and not from a
Raspberry Pi, where the host and the PCIe link differ:

| Model | Input | mAP (float) | mAP (hardware) | FPS (batch 1) | FPS (batch 8) |
|---|---|---:|---:|---:|---:|
| yolov8n | 640×640 | 37.0 | 36.4 | 202 | 438 |
| yolov8s | 640×640 | 44.6 | 43.9 | 110 | 208 |
| yolov11n | 640×640 | 39.0 | 37.5 | 157 | 371 |
| yolov11s | 640×640 | 46.3 | 45.1 | 92.0 | 192 |

Source: [hailo_model_zoo/docs/public_models/HAILO8L](https://github.com/hailo-ai/hailo_model_zoo/blob/master/docs/public_models/HAILO8L/HAILO8L_object_detection.rst)

Two things to take from this table. First, **yolov8n at 202 FPS leaves the
control loop far more headroom than it can use** — §3 of the control design
shows the loop bandwidth is capped near 1 Hz by latency, so the useful question
is latency, not frame rate. Second, Hailo's own float-to-hardware gap on COCO is
0.6–1.5 mAP points, which is the right order of magnitude to expect from INT8
quantisation and a useful sanity check on the numbers in
[benchmarks.md](benchmarks.md).

## 7. Troubleshooting

| Symptom | Cause |
|---|---|
| `hailo_platform` import fails | Installed via apt, not pip; venv needs `--system-site-packages` |
| `hailortcli` finds no device | PCIe link; check `dmesg \| grep -i hailo` |
| Pipeline runs, zero detections | Missing sigmoid on the classification branches (§3) |
| Detections in the wrong place | Input format mismatch: on-chip normalisation expects uint8 |
| Throughput about half of published | PCIe Gen 2; set `dtparam=pciex1_gen=3` |
| Latency spikes every few seconds | Thermal throttling; check `vcgencmd measure_temp` |

---

**See also:** [architecture.md](architecture.md) ·
[benchmarks.md](benchmarks.md) · [hardware.md](hardware.md)

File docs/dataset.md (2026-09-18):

# Dataset

## DUT Anti-UAV

Accuracy in this project is reported on the **DUT Anti-UAV** detection
benchmark: a public, peer-reviewed, single-class UAV detection dataset.

> Jie Zhao, Jingshu Zhang, Dongdong Li, Dong Wang.
> *Vision-based Anti-UAV Detection and Tracking.*
> IEEE Transactions on Intelligent Transportation Systems, 2022.
> <https://github.com/wangdongdut/DUT-Anti-UAV>

It was chosen over the easy alternatives for three reasons: it is published with
a paper and a baseline table, so results are comparable to something; it is
ground-to-air, which is the geometry this turret actually sees, unlike
drone-mounted datasets such as VisDrone; and its object-size distribution is
brutal in exactly the way real UAV detection is.

No images are vendored in this repository. Everything is fetched by script.

```bash
pip install -e ".[bench]"
python tools/fetch_dut_antiuav.py --out data/dut_antiuav
python tools/prepare_dataset.py   --root data/dut_antiuav
```

The archives are hosted on Google Drive by the authors, so `fetch` needs
`gdown`. If Google rate-limits the download, the script points you at the Baidu
mirror in the upstream README. The test split alone (271 MB) is enough to
reproduce every accuracy number here.

## What is in it

Measured by `tools/prepare_dataset.py` and written to
`data/dut_antiuav/stats.json`:

| Split | Images | Objects | Background images |
|---|---:|---:|---:|
| train | 5,200 | 5,243 | 3 |
| val | 2,600 | 2,620 | 0 |
| test | 2,200 | 2,245 | 0 |

Split sizes match those published in the paper, and `fetch_dut_antiuav.py`
verifies the counts after extraction.

### Object size — the whole problem in one table

Using the COCO thresholds (small `< 32²` px, large `≥ 96²` px):

| Split | Small | Medium | Large | Median object area |
|---|---:|---:|---:|---:|
| train | 2,723 (52%) | 1,857 (35%) | 663 (13%) | 0.047% of the frame |
| val | 1,401 (53%) | 892 (34%) | 327 (12%) | 0.046% of the frame |
| test | 848 (38%) | 836 (37%) | 561 (25%) | 0.091% of the frame |

The median object covers **under one tenth of one percent of the frame**. The
smallest is 1.9 × 10⁻⁵ of the frame — about 25 pixels in a 1280 × 720 image.
The largest covers 70%.

Three consequences that shape the rest of the project:

1. **`AP_small` is close to the whole story.** An aggregate AP can look
   respectable while the model has quietly stopped seeing distant targets, which
   are precisely the ones worth detecting early. Every result table here breaks
   AP down by size.
2. **Input resolution is not negotiable.** Dropping from 640 to 416 to buy frame
   rate throws away the small objects first. The NPU exists so this trade does
   not have to be made.
3. **Quantisation is riskier than usual.** Small, low-contrast objects produce
   small activations, which is where INT8's coarse quantisation levels hurt
   most. This is why [benchmarks.md](benchmarks.md) reports the quantised model
   separately rather than assuming the FP32 result carries over.

## Format conversion

`tools/prepare_dataset.py` converts Pascal VOC XML into both layouts:

```
data/dut_antiuav/
├── train/ val/ test/         img/*.jpg + xml/*.xml   (as downloaded)
├── yolo/
│   ├── images/{train,val,test}/   symlinks, not copies
│   └── labels/{train,val,test}/   normalised centre-form
├── coco/{train,val,test}.json     COCO ground truth
├── dut_antiuav.yaml               Ultralytics descriptor
└── stats.json
```

Images are symlinked so the 1.2 GB of JPEGs is not duplicated; on Windows
without Developer Mode this falls back to hardlinks, then to copies.

Two conversion details that are easy to get wrong and invisible on large objects:

- **VOC is inclusive corners; COCO is `[x, y, w, h]`.** Mixing them shifts every
  box by a pixel. On a 20-pixel UAV that is a 5% error in every box.
- **Empty label files are required.** A background image with no `.txt` is
  reported by Ultralytics as *unlabelled* and silently skipped, rather than
  learned from as a negative.

Both are covered by `tests/test_data_and_config.py`.

## Evaluation protocol

`benchmarks/eval_detection.py` scores with `pycocotools` at the standard COCO
IoU sweep (0.50:0.95). Two choices worth stating:

- **Detections are collected at a confidence threshold of 0.001.** COCO AP
  integrates over the precision–recall curve; filtering before scoring truncates
  the curve and *understates* AP. The operating threshold used in the live
  pipeline is a separate decision, made in `configs/`.
- **The scorer is restricted to exactly the images that were run.** With
  `--limit`, scoring a subset of detections against the full ground truth
  collapses every metric in proportion to the subset size. (This was a real bug
  during development: it made a working model look like it had an AP of 0.024.)

## The tracking subset

The same benchmark ships 20 annotated video sequences, used by
`benchmarks/eval_tracking.py`:

```bash
python tools/fetch_dut_antiuav.py --out data/dut_antiuav_tracking --splits tracking
python benchmarks/eval_tracking.py --model runs/train/uav_yolov8n/weights/best.pt
```

Worth stating plainly: **this is a harder task than the single-object-tracking
baselines published with the dataset.** A SOT tracker is handed the ground-truth
box in frame one and only has to follow it. This pipeline is never told where
the target is -- it detects, associates and picks a primary target with no
initialisation. The numbers are therefore not comparable to a SOT leaderboard
and are not presented as if they were.

## Bird discrimination

Birds are the canonical false positive for ground-to-air UAV detection: similar
apparent size, similar sky background, similar motion at a distance. DUT
Anti-UAV contains no labelled birds, so it cannot measure this.

`benchmarks/eval_hard_negatives.py` measures it separately, using bird images
from **Open Images V7** — properly licensed, scriptable to download, and with
per-image labels that let images containing aircraft be excluded. The metric is
a false-positive rate on images guaranteed to contain no UAV, which is the
number that decides whether the turret spends its day chasing pigeons.

---

**See also:** [benchmarks.md](benchmarks.md) · [architecture.md](architecture.md)

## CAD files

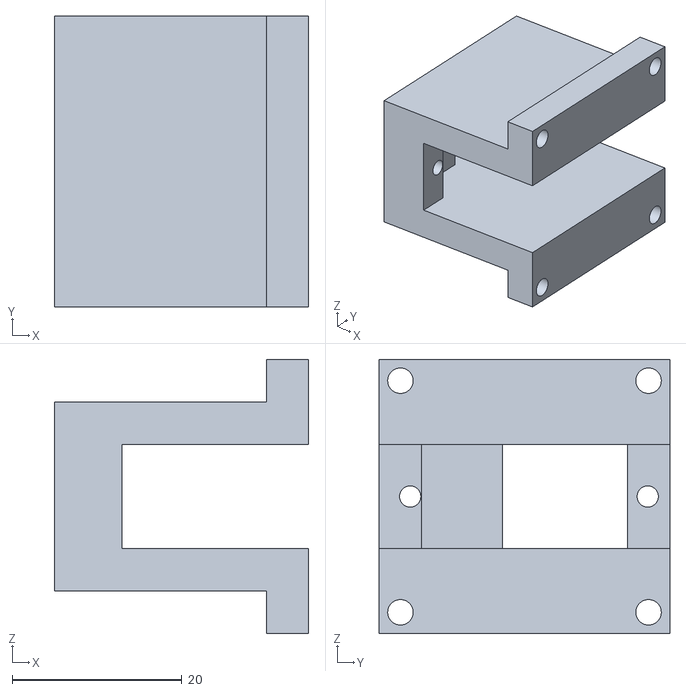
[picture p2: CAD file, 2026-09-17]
hardware/cad/base_plate.stl
30.0 x 34.3 x 32.3

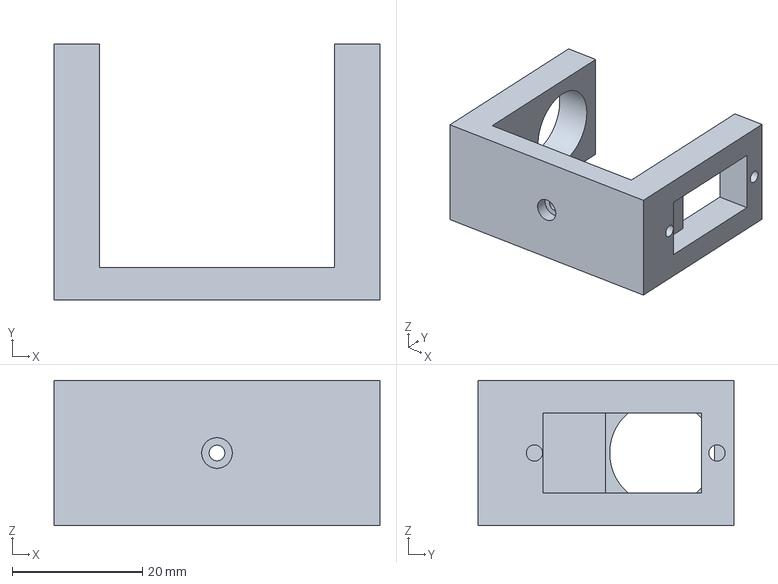
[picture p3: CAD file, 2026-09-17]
hardware/cad/yoke_pan.3mf
50.0 x 39.3 x 22.3 mm

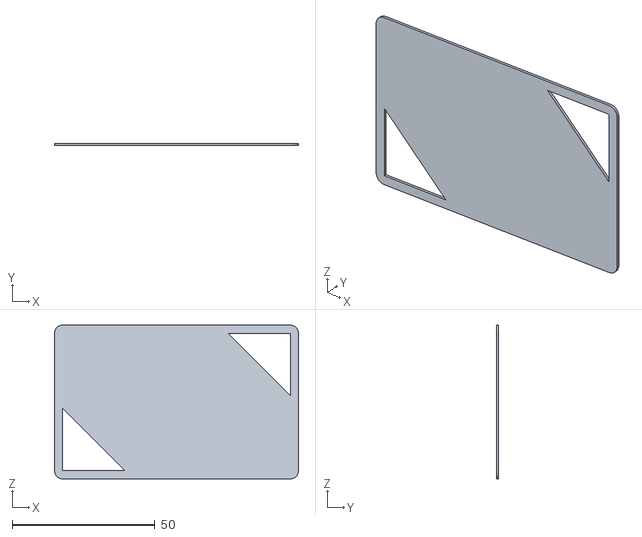
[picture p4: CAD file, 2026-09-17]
hardware/cad/tilt_arm.stl
85.6 x 0.8 x 54.0

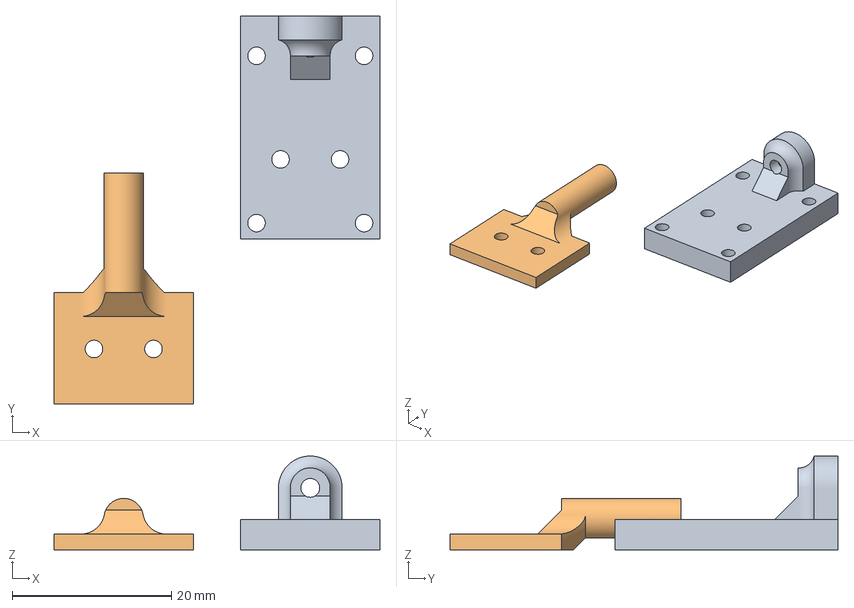
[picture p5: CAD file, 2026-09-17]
hardware/cad/camera_mount_v2.3mf
40.9 x 48.7 x 11.8 mm
attacco_camera_rivisto.stl
attacco_cuscinetto.stl

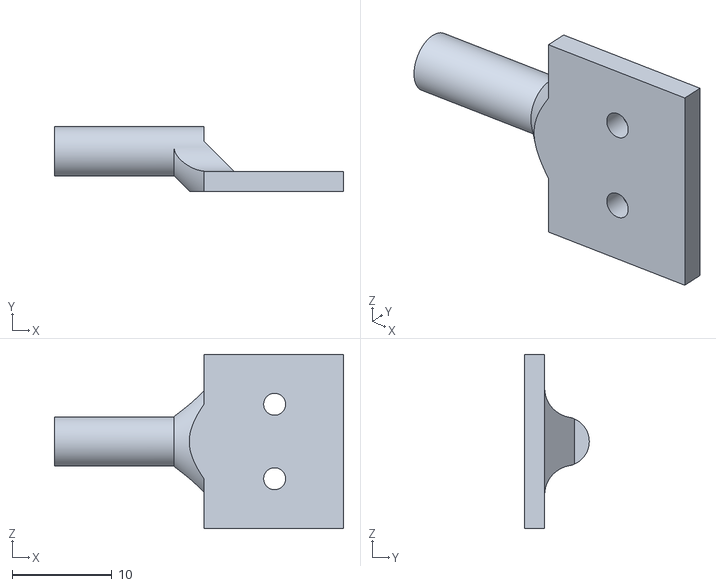
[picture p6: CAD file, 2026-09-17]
hardware/cad/bearing_holder.stl
29.0 x 6.47 x 17.5

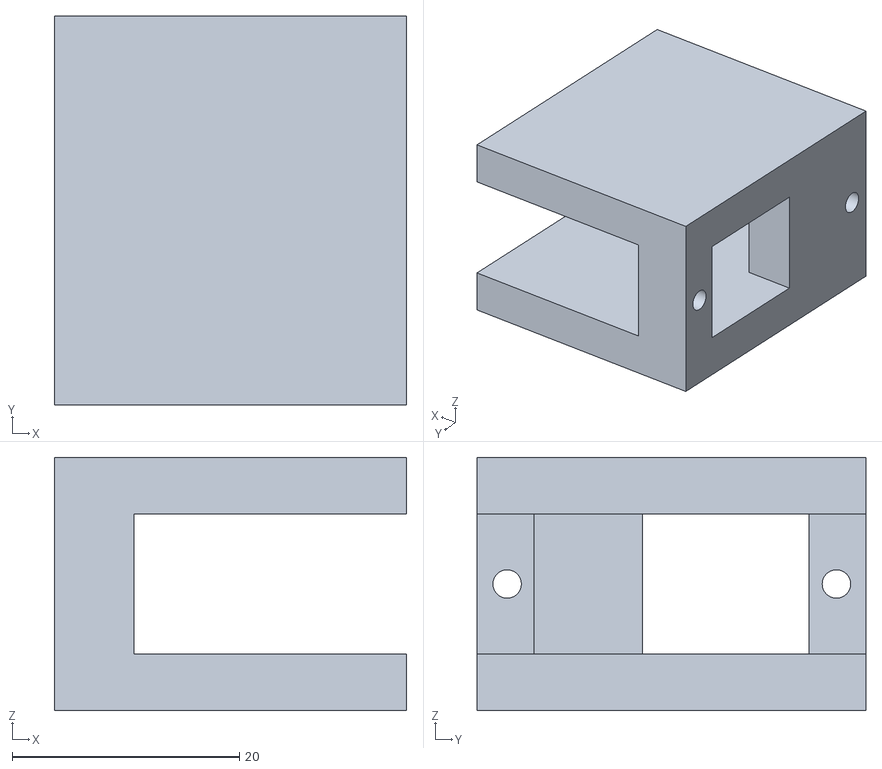
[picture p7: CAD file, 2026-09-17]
hardware/cad/yoke_mg90s_fit_test.stl
31.0 x 34.3 x 22.3

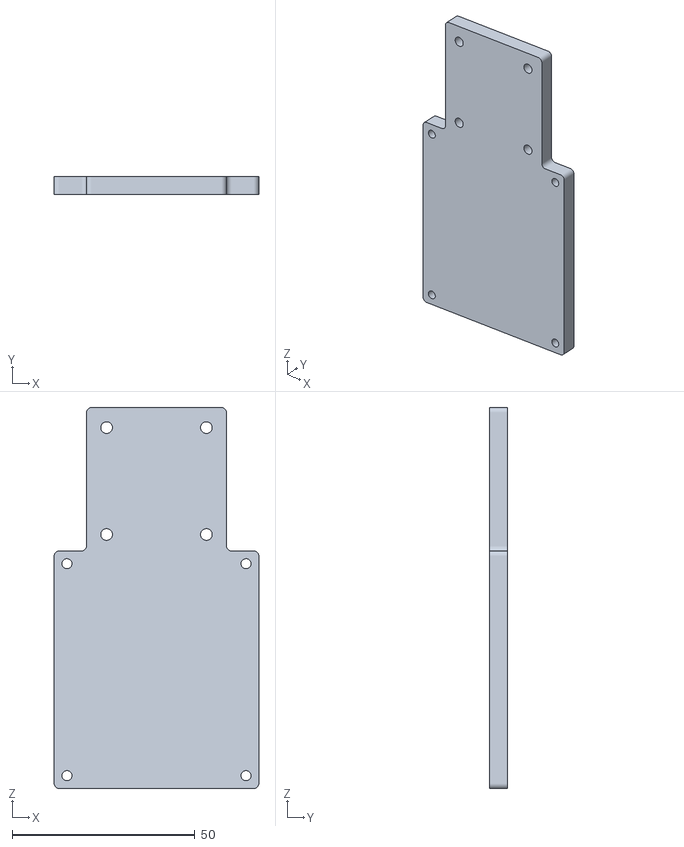
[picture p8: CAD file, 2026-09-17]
hardware/cad/base_rpi5_tray.stl
56.0 x 5.00 x 104.3

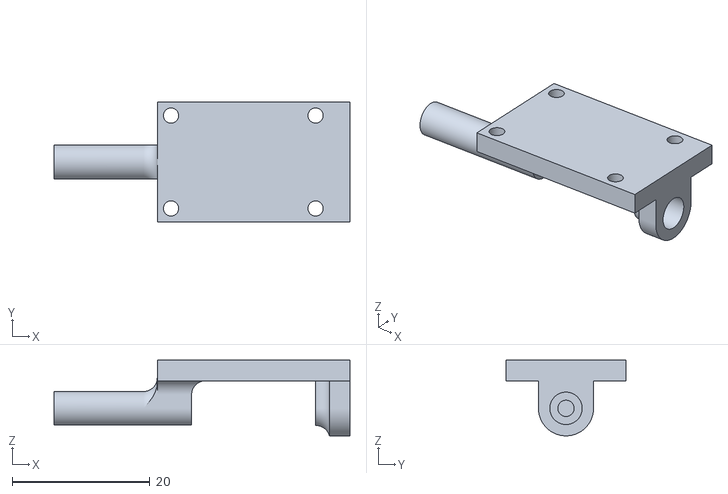
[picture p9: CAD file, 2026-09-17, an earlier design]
hardware/cad/camera_mount_v1.stl
43.0 x 17.5 x 11.0

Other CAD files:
hardware/cad/camera_mount_v2.stl
hardware/cad/yoke_pan.stl

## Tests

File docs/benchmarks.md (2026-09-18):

# Benchmarks

Every table below is generated from JSON files in
[`benchmarks/results/`](../benchmarks/results) by
`python benchmarks/make_report.py`. Nothing here is typed in by hand, and every
number traces back to a script you can re-run.

Results are labelled by kind:

- **measured** — produced by running code on real data on the stated hardware.
- **simulation** — produced by the closed-loop model in
  [`simulator.py`](../src/uavtrack/control/simulator.py). Useful for comparing
  configurations, not a substitute for a hardware measurement.
- **published** — figures from a vendor or a paper, cited and attributed.

---

## 1. Detection accuracy — DUT Anti-UAV test split

COCO protocol, 2,200 images, single class, IoU 0.50:0.95. See
[dataset.md](dataset.md) for the benchmark and the evaluation protocol.

```bash
python benchmarks/eval_detection.py \
    --model runs/train/uav_yolov8n/weights/best.pt \
    --tag yolov8n-fp32-pytorch
```

<!-- BEGIN GENERATED: detection -->
| Model | Backend | AP | AP50 | AP75 | AP_S | AP_M | AP_L | Images |
| ---: | ---: | ---: | ---: | ---: | ---: | ---: | ---: | ---: |
| `yolov8n-fp32-onnx` | onnx:cpu | 0.556 | 0.894 | 0.585 | 0.418 | 0.578 | 0.717 | 2200 |
| `yolov8n-fp32-pytorch` | ultralytics:cpu | 0.543 | 0.886 | 0.574 | 0.395 | 0.567 | 0.713 | 2200 |
| `yolov8n-int8-onnx` | onnx:cpu | 0.518 | 0.875 | 0.522 | 0.358 | 0.536 | 0.709 | 2200 |
| `yolov8n-negatives` | ultralytics:cpu | 0.503 | 0.865 | 0.514 | 0.356 | 0.559 | 0.657 | 2200 |
<!-- END GENERATED: detection -->

`AP_S` is the column to read first. Over half the objects in this dataset are
below 32×32 pixels, and an aggregate AP can look respectable while the model has
stopped seeing distant targets — which are the ones worth detecting early.

### The resize kernel, and a correctness proof

The ONNX row above scores *higher* than the PyTorch row it was exported from.
Same weights, so either the decode is wrong or the preprocessing differs.

It is the preprocessing. Ultralytics resizes with bilinear interpolation;
[`preprocess.py`](../src/uavtrack/detect/preprocess.py) uses `cv2.INTER_AREA`
when shrinking. Re-scoring the same graph on the same images with bilinear
forced back on isolates the effect:

```bash
python benchmarks/eval_detection.py     --model models/uav_yolov8n_640.onnx     --downscale linear --tag ablation-inter-linear
```

<!-- BEGIN GENERATED: preprocessing-ablation -->
| Metric | Ultralytics (bilinear) | This decode, bilinear | This decode, `INTER_AREA` | Area &minus; bilinear |
| ---: | ---: | ---: | ---: | ---: |
| `AP` | 0.5427 | 0.5428 | 0.5557 | +0.0130 |
| `AP50` | 0.8858 | 0.8860 | 0.8935 | +0.0075 |
| `AP75` | 0.5738 | 0.5669 | 0.5852 | +0.0182 |
| `AP_small` | 0.3950 | 0.3966 | 0.4185 | +0.0219 |
| `AP_medium` | 0.5674 | 0.5665 | 0.5779 | +0.0113 |
| `AP_large` | 0.7129 | 0.7155 | 0.7175 | +0.0020 |
<!-- END GENERATED: preprocessing-ablation -->

**The decode is correct.** With the kernel matched, this implementation lands
within 0.0001 AP and 0.0002 AP50 of Ultralytics across 2,200 images. The box
decode, the coordinate transform and the NMS here are hand-written NumPy, and
they reproduce the reference to four decimal places. That is the strongest
statement available about a reimplementation: not "it looks right", but "it
scores the same".

#### Where the gain comes from, and where it does not

The aggregate gain is real but it is an average over a benchmark with four
source resolutions, and the kernel does nothing at all for some of them:

```bash
python benchmarks/analyse_resize_ablation.py
```

<!-- BEGIN GENERATED: resize-by-resolution -->
| Source | Downscale | Images | AP `area` | AP `linear` | &Delta; AP | &Delta; AP_S |
| ---: | ---: | ---: | ---: | ---: | ---: | ---: |
| 1920x1080 | 3.00:1 | 1348 | 0.4769 | 0.4540 | +0.0229 | +0.0236 |
| 1280x720 | 2.00:1 | 836 | 0.6721 | 0.6721 | +0.0000 | +0.0000 |
| 960x720 | 1.50:1 | 8 &dagger; | 0.7969 | 0.7969 | +0.0000 | +0.0000 |
| 640x360 | 1.00:1 | 6 &dagger; | 0.5864 | 0.5864 | +0.0000 | +0.0000 |
| 1440x1080 | 2.25:1 | 1 &dagger; | 0.6000 | 0.2500 | +0.3500 | +0.0000 |
| 696x643 | 1.09:1 | 1 &dagger; | 0.6243 | 0.6243 | +0.0000 | +0.0000 |

&dagger; fewer than 50 images; shown for completeness, not interpretable.
<!-- END GENERATED: resize-by-resolution -->

Every point of the improvement comes from the 1920x1080 images. At 1280x720 the
delta is not small, it is **exactly zero** -- because at an exact 2:1 downscale
OpenCV's bilinear filter averages the same 2x2 block that `INTER_AREA` does and
the two kernels produce bit-identical pixels on x86. On aarch64 -- what the Pi runs -- OpenCV's NEON path rounds differently and about a third of the pixels come out one level apart, which cannot change a detection but does mean "identical" is not a portable claim. That is pinned by a
test on both architectures, not inferred -- and the test asserted plain
bit-identity until it was first run on the Pi, where it failed for exactly this
reason.

The mechanism at 3:1 is not "area-averaging keeps more signal". Averaged over
sub-pixel offsets both kernels pass the *same* total energy. The difference is
variance. Rendering a one-pixel-wide line -- what a distant UAV becomes at
range -- at 24 sub-pixel offsets:

| Kernel | min | max | mean |
|---|---:|---:|---:|
| `INTER_AREA` | 85 | 85 | 85.0 |
| `INTER_LINEAR` | **0** | 255 | 85.0 |

Bilinear at 3:1 samples two columns of every three. The target lands on a
sample and comes through at full intensity, or lands between samples and
disappears completely; it is worse than area-averaging at 16 of 24 offsets. A
detector gains nothing from the offsets where bilinear over-delivers and fails
outright on the ones where the target is gone. Area-averaging trades the peaks
away for a response that does not depend on where the drone happens to sit
within a source pixel. See
[`test_preprocess.py`](../tests/test_preprocess.py).

#### What this means for the deployed configuration

**It does not apply to it.** [`configs/rpi5_hailo8l.yaml`](../configs/rpi5_hailo8l.yaml)
captures at 1280x720, which is exactly 2:1 into a 640 network -- the row where
the measured delta is zero. The honest reading of the ablation is:

- the `INTER_AREA` default is the right default, and costs nothing;
- it is worth roughly two points of `AP_small` **at non-dyadic downscale ratios**;
- at this project's own capture resolution it is a no-op, and quoting the
  aggregate number as a property of the turret would be quoting a true
  measurement to support a false claim.

It also suggests something testable on hardware: capturing at 1920x1080 and
letterboxing 3:1 may detect small targets better than capturing at 720p, for
reasons that have nothing to do with the extra pixels reaching the network.
That has not been measured here, and is listed in
[What this does not do](../README.md#what-this-does-not-do).

### Quantisation, and how it fails

The Hailo-8L is an INT8 accelerator, so the model that runs on the turret is not
the model that was trained. Reporting only FP32 numbers would be reporting a
model this project does not run.

Compiling a HEF needs the Hailo Dataflow Compiler, which requires a developer
account and does not run in CI. Static INT8 quantisation through ONNX Runtime
does run anywhere and shares the mechanisms that matter: affine quantisation,
calibration on a sample of training images, and the same sensitivities. It is a
**proxy** for the Hailo quantiser, not a substitute, and the `-int8-onnx` tags
above say so.

Getting it to work at all took three findings, each reproducible with
`tools/quantize_onnx.py`:

| Recipe | Result |
|---|---|
| Whole graph, per-tensor, MinMax | **zero detections** at any threshold |
| Whole graph, per-channel, opset 11 | fails to load: `INVALID_GRAPH` |
| Whole graph, per-channel, opset 13 | **zero detections** |
| Whole graph, per-channel, percentile calibration | **zero detections** |
| Convolutions only, decode tail left in FP32 | works |

**Why the whole-graph recipes collapse.** The final `Concat` in the YOLOv8 head
joins decoded box coordinates, which span 0 to 640 in pixel units, with class
scores, which span 0 to 1. One quantisation scale has to cover both, and at
uint8 that scale is roughly 2.5 units per level — so every class score rounds to
zero. The model is not degraded, it is silenced, and silenced in a way that
looks exactly like a working pipeline that happens to find nothing.

**Why opset 11 cannot do per-channel.** Opset 11's `QuantizeLinear` has no
`axis` attribute, so the graph is invalid. It surfaces as `INVALID_GRAPH` at
session creation, naming nothing relevant. `tools/export_onnx.py` therefore
exports opset 13, which the Hailo compiler also accepts.

**The fix.** Quantise the convolutions and keep the head's decode tail — 24
cheap element-wise nodes — in floating point. All the compute is in the
convolutions, so the model is still 3.5× smaller. Hailo's compiler runs its own
mixed-precision analysis for the same reason, which is part of why the HEF is
the measurement that ultimately counts.

For scale, Hailo's own published float-to-hardware gap on COCO is 0.6–1.5 mAP
points for the YOLOv8/YOLO11 family (§5).

---

### The training run behind these numbers

```bash
python tools/train_uav.py     --data data/dut_antiuav/dut_antiuav_fastval.yaml     --epochs 10 --imgsz 640 --batch 16 --device cpu     --workers 8 --cache ram --close-mosaic 3
```

YOLOv8n from the COCO-pretrained checkpoint, 10 epochs on the 5,200-image
training split, CPU only, 3 h 52 m wall clock. The exact arguments are written
to `runs/train/uav_yolov8n/train_config.json` next to the weights.

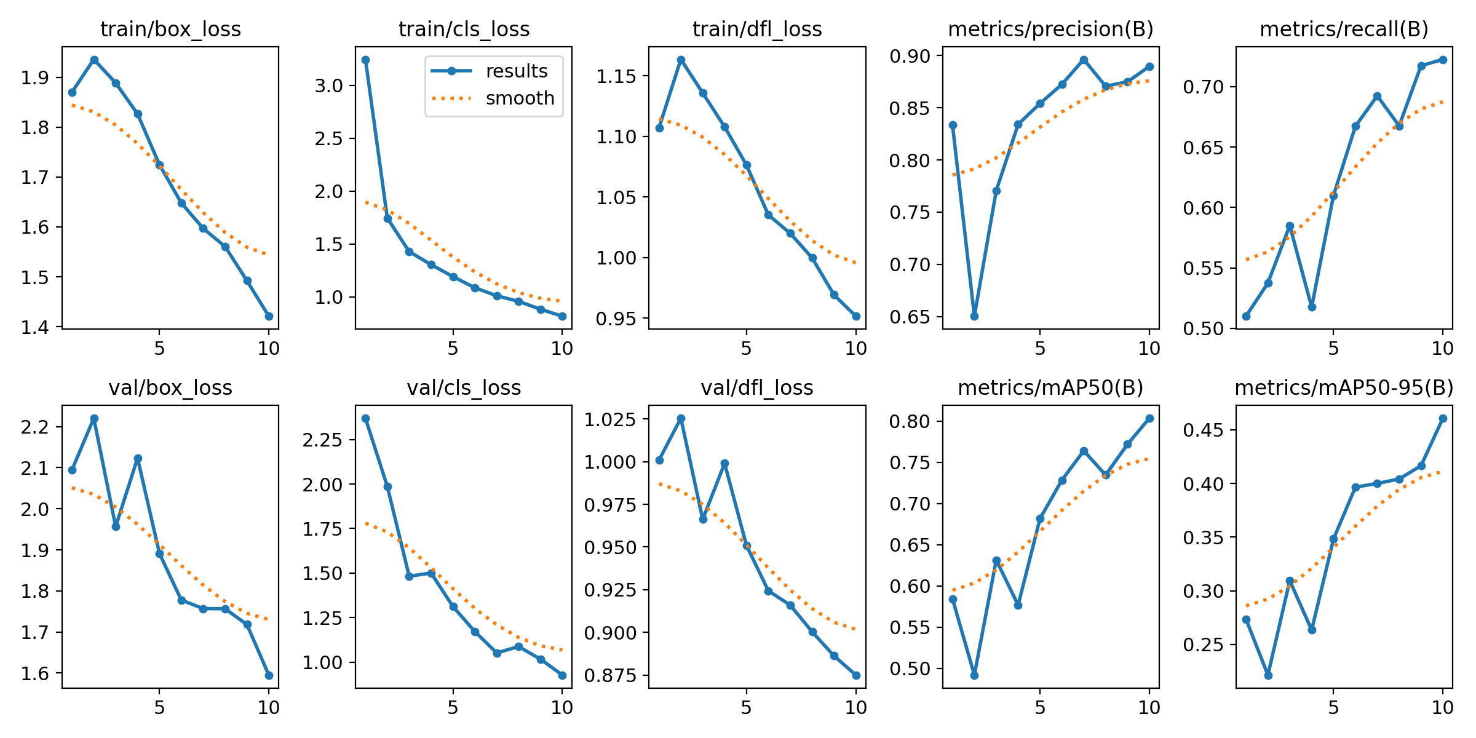
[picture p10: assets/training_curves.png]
Training curves


**These curves are not the reported accuracy.** Per-epoch validation runs
against a 400-image subset (`dut_antiuav_fastval.yaml`), because validating on
the full split after every CPU epoch costs more than the epoch does. The subset
is for watching the curve and for checkpoint selection; every number in §1 is
measured on the untouched 2,200-image test split.

Two things in the curve are worth knowing if you re-run this:

- mAP50 oscillates hard for the first five epochs -- 0.58, 0.49, 0.63, 0.58,
  0.68 -- while the classification loss falls monotonically throughout. On a
  400-image subset the metric is noisy enough to look like divergence when
  nothing is wrong. Watch the loss.
- The last three epochs run with mosaic augmentation disabled
  (`--close-mosaic 3`), and the step is visible: 0.772 to 0.804 mAP50 on the
  final epoch.

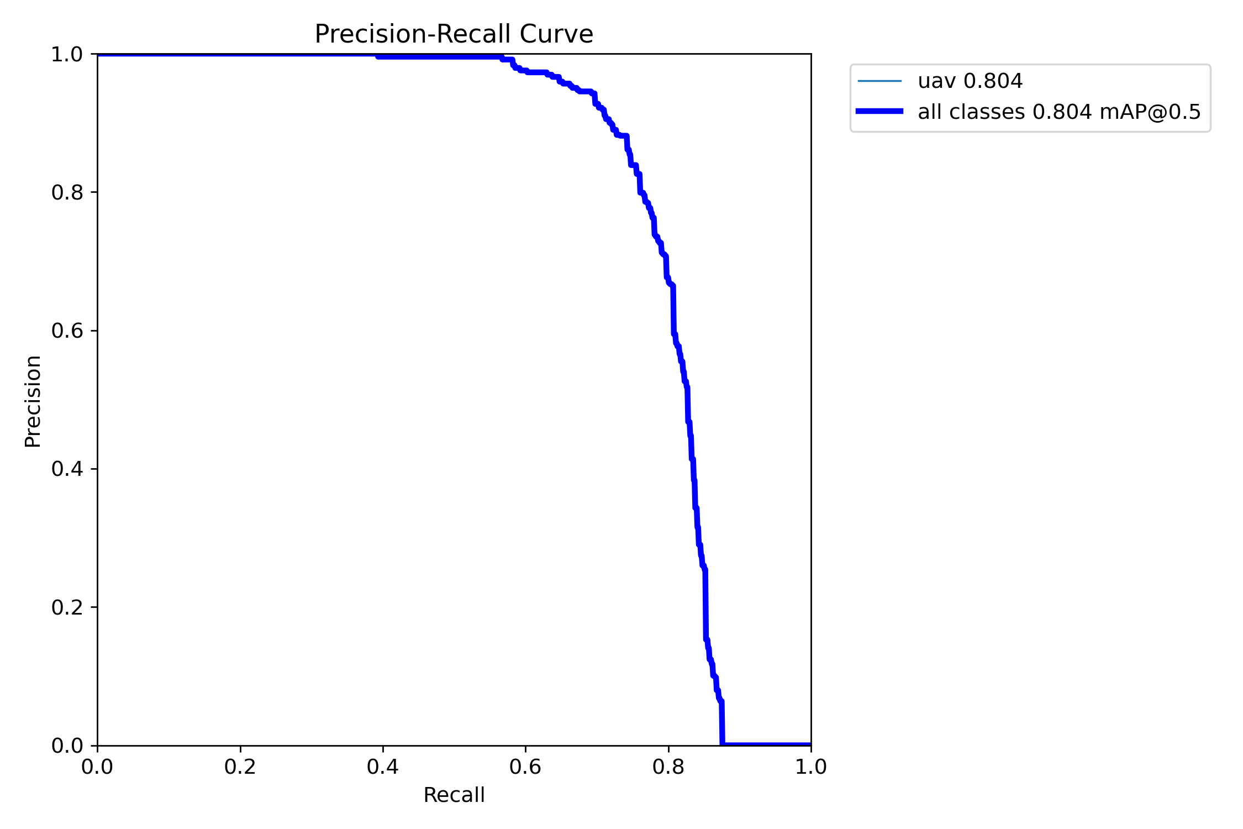
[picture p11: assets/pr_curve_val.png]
Precision-recall, validation subset


Ten CPU epochs is a deliberately modest budget -- enough to produce a detector
worth measuring end to end, not enough to be a serious attempt at the benchmark.
A longer schedule on a GPU, and birds as labelled negatives, are the two obvious
improvements.

## 2. Latency and throughput

```bash
python benchmarks/bench_latency.py --model models/uav_yolov8n_640.hef --frames 300
```

<!-- BEGIN GENERATED: latency -->
| Model | Host | Backend | Inference (ms) | End to end (ms) | p95 | p99 | FPS |
| ---: | ---: | ---: | ---: | ---: | ---: | ---: | ---: |
| `yolov8n-fp32-onnx-rpi5cpu` | Pi 5 CPU | onnx:cpu | 153.6 | 153.9 | 180.9 | 183.0 | 6.5 |
| `yolov8n-int8-onnx-rpi5cpu` | Pi 5 CPU | onnx:cpu | 75.0 | 75.3 | 93.6 | 96.0 | 13.3 |
| `yolov8n-fp32-onnx` | x86 desktop | onnx:cpu | 39.8 | 40.1 | 45.2 | 50.4 | 24.9 |
| `yolov8s-int8-hailo8l` | Pi 5 + Hailo-8L | hailo8l | 19.9 | 20.2 | 22.8 | 23.0 | 49.5 |
| `yolov8n-int8-hailo8l` | Pi 5 + Hailo-8L | hailo8l | 13.6 | 13.8 | 14.0 | 14.2 | 72.7 |
<!-- END GENERATED: latency -->

Quote the **p95**, not the mean. A control loop is hurt by the tail: one 200 ms
frame in fifty does more damage to a pointing solution than a mean that is 5 ms
worse, because the tracker's extrapolation error grows with the gap and the
controller cannot know a frame is late until it arrives.

`control.latency_s` in your config should be set from the median-to-p95 range
measured on **your** hardware.

### What that costs in degrees, on the real board

Every row below was measured on the target hardware -- a Pi 5 with 4 GB and
Debian 13, over SSH, against 80 real frames from the test split rather than
synthetic ones. Feeding each measured latency back into the closed-loop
simulation gives the number the whole project is about:

| Configuration | Inference | Tail (p99 over median) | FPS | Steady-state pointing error |
|---|---:|---:|---:|---:|
| Pi 5 CPU, FP32 | 153.6 ms | +18.9% | 6.5 | 1.41&deg; |
| Pi 5 CPU, INT8 | 75.0 ms | +27.4% | 13.3 | 0.99&deg; |
| **Hailo-8L, INT8** | **13.6 ms** | **+3.0%** | **72.7** | **0.65&deg;** |

```bash
python benchmarks/bench_latency.py --model models/yolov8n_h8l.hef --tag yolov8n-int8-hailo8l
python -m uavtrack.cli simulate --trajectory circular --duration 20 --latency-ms 14
```

**The accelerator is 11.3x faster than the Pi's CPU** on the same architecture
and input size, and it more than halves the steady-state pointing error.

**It also makes the latency deterministic, which may matter more.** The CPU's
p99 sits 19-27% above its median; the Hailo's sits 3% above. This page has
always said to quote the p95 rather than the mean, because a control loop is
hurt by the tail: the tracker's extrapolation error grows with the gap and the
controller cannot know a frame is late until it arrives. A jitter band of 3%
instead of 27% is worth having independently of the speedup.

**Quantisation alone is worth 2.05x on the CPU**, 153.6 ms to 75.0 ms, on a
board with no NPU involved. If you have no accelerator, that is still most of
the exercise.

#### What these accelerator numbers are, and are not

The HEF is Hailo's own **COCO-trained yolov8n** from the Model Zoo, not the UAV
detector trained here, because compiling a HEF needs the Dataflow Compiler and
that is x86_64 Linux only (see &sect;5 and docs/hailo-deployment.md).

So the **latency is representative** -- identical architecture, identical
640x640 input, same compiler, same device, same board -- and the **accuracy is
not ours**. No detection metric in &sect;1 was measured on the accelerator. When
the UAV model is compiled, it should land at or slightly under these times,
being the same network with one class instead of eighty.

---

## 3. Tracking — DUT Anti-UAV sequences

```bash
python tools/fetch_dut_antiuav.py --out data/dut_antiuav_tracking --splits tracking
python benchmarks/eval_tracking.py --model runs/train/uav_yolov8n/weights/best.pt
```

<!-- BEGIN GENERATED: tracking -->
| Model | Sequences | Frames | Success AUC | Success@0.5 | P@20px | Recall | Re-acquisitions |
| ---: | ---: | ---: | ---: | ---: | ---: | ---: | ---: |
| `yolov8n-fp32-pytorch` | 20 | 24,804 | 0.593 | 0.748 | 0.790 | 0.816 | 193 |
<!-- END GENERATED: tracking -->

**Not comparable to the dataset's SOT baselines.** A single-object tracker is
handed the ground-truth box in frame one and only has to follow it. This
pipeline is never told where the target is — it detects, associates and selects
a primary target with no initialisation. That is a strictly harder task, and the
numbers are reported as what they are.

*Recall* is the column that keeps the others honest: a tracker can post a good
success curve while answering on only a third of the frames. *Re-acquisitions*
counts identity changes on the primary target — each one is a moment where a
real turret would have swung somewhere else.

---

## 4. Bird discrimination

Birds are the canonical false positive for ground-to-air UAV detection: similar
apparent size at range, same sky background, similar motion. DUT Anti-UAV
contains no labelled birds, so this is measured separately on Open Images V7
bird images with aircraft classes excluded.

```bash
python benchmarks/eval_hard_negatives.py --model runs/train/uav_yolov8n/weights/best.pt --fetch
```

<!-- BEGIN GENERATED: hard-negatives -->
| Model | Bird images | Threshold | False-positive rate | Threshold for 1% |
| ---: | ---: | ---: | ---: | ---: |
| `yolov8n-fp32-pytorch` | 593 | 0.35 | 23.44% | 0.9 |
| `yolov8n-negatives` | 593 | 0.35 | 7.08% | 0.7 |
<!-- END GENERATED: hard-negatives -->

The metric is the fraction of bird images that produce at least one UAV
detection at the deployed threshold — that is, how often the turret would swing
onto a pigeon.

### Fixing it: birds as training background

`tools/add_hard_negatives.py` fetches bird photographs and installs them as
background images -- an empty label file, so any detection on them becomes loss.
Four epochs of fine-tuning on top of the existing weights:

```bash
python tools/add_hard_negatives.py --count 600
python tools/train_uav.py --data data/dut_antiuav/dut_antiuav_negatives.yaml     --model runs/train/uav_yolov8n/weights/best.pt --epochs 4 --close-mosaic 2
```

The negatives are drawn from the Open Images **train** split while the benchmark
scores the **validation** split, so the two are disjoint by construction; the
script refuses to run otherwise, and the two image sets were also checked for
overlap by filename. Training on the images you are about to be scored on is an
easy mistake to make and produces a spectacular, meaningless result.

The headline: **the false-positive rate on birds falls from 23.4% to 7.1%** at
the operating threshold. Taken alone that number is worthless, because raising
the confidence threshold achieves the same thing for free. Worse, the fine-tuned
model is *behind* on the drone benchmark -- AP 0.543 to 0.503, AP50 0.886 to
0.865. Read those two facts together and the obvious conclusion is that the
model simply became timid.

It did not, and the way to tell is to compare at **matched bird false-positive
rates**:

```bash
python benchmarks/analyse_negatives_tradeoff.py
```

<!-- BEGIN GENERATED: negatives-tradeoff -->
| Target bird FP | Baseline thr / actual | Recall | With negatives thr / actual | Recall | &Delta; |
| ---: | ---: | ---: | ---: | ---: | ---: |
| 10.0% | 0.60 / 9.9% | 0.713 | 0.25 / 9.6% | **0.821** | +15% |
| 6.0% | 0.70 / 5.7% | 0.600 | 0.40 / 5.2% | **0.783** | +31% |
| 3.5% | 0.80 / 2.2% | 0.360 | 0.60 / 2.0% | **0.661** | +83% |
| 2.0% | 0.90 / 0.2% | 0.033 | 0.70 / 0.8% | **0.485** | +1392% &dagger; |

&dagger; the two models' actual bird rates differ by more than 1.5x here, so this row is not a matched comparison and its relative gain is overstated.
<!-- END GENERATED: negatives-tradeoff -->

At every operating point, with birds suppressed equally hard or harder, the
fine-tuned model finds substantially more drones. The baseline needs a
confidence of 0.70 to get birds down to 5.7%, and at 0.70 it has lost 40% of the
drones; the fine-tuned model reaches a *lower* bird rate at 0.40, where it still
sees 78%.

So why is its AP lower? Because AP integrates the whole precision-recall curve,
including the low-confidence tail no deployment operates in. The fine-tuned
model is worse there and better everywhere a turret would actually be set. AP is
the right summary for a detector in general and the wrong one for this decision.

Two caveats on the result:

- **Four epochs on CPU is a small budget** for absorbing 600 new images, 10% of
  the training set. A full training run with the negatives included from the
  start would very likely beat both models rather than trading against one.
- **Bird photographs are not birds in flight against sky.** Open Images contains
  perched birds, close-ups and birds indoors. The rate measured here is a proxy
  for the deployment case, better than no measurement and not the same thing.

Both models are kept. Which one to deploy depends on whether false alarms or
missed drones cost more, and that is an application question, not a benchmark
one.

---

## 5. Published Hailo-8L throughput

Not measurements from this project. These are **Hailo's published Model Zoo
figures on COCO**, measured on an Intel Core i5-9400 over PCIe Gen 3 ×4 with
Dataflow Compiler v2.19.0 — a different host and a different link from a
Raspberry Pi. Included because they set the expectation for what the accelerator
can do:

| Model | Input | mAP (float) | mAP (hardware) | FPS (batch 1) | FPS (batch 8) |
|---|---|---:|---:|---:|---:|
| yolov8n | 640×640 | 37.0 | 36.4 | 202 | 438 |
| yolov8s | 640×640 | 44.6 | 43.9 | 110 | 208 |
| yolov11n | 640×640 | 39.0 | 37.5 | 157 | 371 |
| yolov11s | 640×640 | 46.3 | 45.1 | 92.0 | 192 |

Source: [Hailo Model Zoo, HAILO8L object detection](https://github.com/hailo-ai/hailo_model_zoo/blob/master/docs/public_models/HAILO8L/HAILO8L_object_detection.rst)

### Published against measured, and where the difference goes

Hailo publishes 202 FPS for yolov8n; this project measures 72.7 FPS for the same
HEF on a Pi 5. That gap is worth decomposing rather than explaining away, and it
is the reason the table above is kept separate from every other number here:

| | FPS | What the step costs |
|---|---:|---|
| Hailo published, Intel host, PCIe Gen 3 x4 | 202 | — |
| Pi 5, `hailortcli` raw, no Python | 117.7 | the host and a **x1** link |
| Pi 5, this project's pipeline | 72.7 | this project's synchronous wrapper |

The first step is the board. The Pi 5 negotiates PCIe **8 GT/s at width x1**
(`current_link_width` is 1 while the Hailo-8L advertises `max_link_width` 4), so
it has a quarter of the lanes Hailo's Intel host used. Nothing in software
recovers that.

The second step is ours. `HailoDetector` waits for each frame to come back
before sending the next, where Hailo's harness keeps several in flight. For a
tracking turret that is the right trade -- what the controller needs is the
newest possible answer, not the largest number of answers -- but it costs about
5 ms per frame of pipeline bubble and it should be stated rather than buried.

None of which changes the conclusion: §6 shows loop bandwidth is capped near
1 Hz by latency, so 72.7 FPS is already an order of magnitude more frames than
the loop can use. The useful question for this system is latency, not frame
rate.

---

## 6. Closed-loop pointing — simulation

**These are simulation results.** The servo model — transport delay, first-order
lag, hard slew-rate limit — is documented in
[`plant.py`](../src/uavtrack/control/plant.py), and what it does *not* model
(backlash, stiction, boresight misalignment, structural flex) is listed in
[control-design.md](control-design.md) §9.

```bash
python benchmarks/bench_control.py --study all
```

### 6.1 Pointing error against sense-to-act latency

Target orbiting at 14 °/s; mean of five seeds; steady state after 2 s.

<!-- BEGIN GENERATED: control-latency -->
| Sense-to-act latency | RMS error | Peak error | In frame |
| ---: | ---: | ---: | ---: |
| 10 ms | 0.68° | 1.03° | 100% |
| 20 ms | 0.69° | 1.05° | 100% |
| 30 ms | 0.73° | 1.14° | 100% |
| 45 ms | 0.83° | 1.21° | 100% |
| 60 ms | 0.87° | 1.24° | 100% |
| 80 ms | 1.01° | 1.40° | 100% |
| 120 ms | 1.21° | 1.63° | 100% |
| 160 ms | 1.45° | 1.93° | 100% |
| 200 ms | 1.83° | 2.37° | 100% |
| 300 ms | 2.77° | 4.48° | 100% |
<!-- END GENERATED: control-latency -->

This is the table that justifies the accelerator. Inference time enters the
control loop as dead time, dead time caps the achievable loop bandwidth, and
bandwidth is what keeps a manoeuvring target centred.
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

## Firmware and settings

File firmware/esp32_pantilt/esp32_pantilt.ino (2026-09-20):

// Pan/tilt turret controller for the uavtrack project.
//
// Listens for framed commands from a Raspberry Pi over USB serial and drives
// two MG90S servos plus one effector output (relay or logic-level MOSFET).
//
// The firmware's job is to be the part of the system that is boring and safe.
// Everything clever happens on the Pi; everything here exists so that a crash,
// a yanked cable or a corrupted byte leaves the turret in a known state:
//
//   * Failsafe. No valid frame for FAILSAFE_TIMEOUT_MS and the effector is cut
//     and the servos are detached. A stalled host must not leave the turret
//     energised and pointing somewhere.
//   * Framing. Commands are CRC-checked (see protocol.h). A corrupt frame is
//     counted and dropped, never acted on.
//   * Rate limiting. Commanded angles are slew-limited here as well as on the
//     Pi, so a bad command cannot ask the servos for a step they would answer
//     with a current spike big enough to brown out the board.
//
// Wiring and power notes are in docs/hardware.md. The short version: do not
// power the servos from the ESP32's regulator, and tie all grounds together.

#include <ESP32Servo.h>

#include "protocol.h"

// ---------------------------------------------------------------- pin mapping
static const int PIN_PAN = 13;
static const int PIN_TILT = 12;
static const int PIN_EFFECTOR = 21;

// ------------------------------------------------------------------ behaviour
static const uint32_t BAUD_RATE = 500000;
static const uint32_t FAILSAFE_TIMEOUT_MS = 500;
// 50 Hz, not 5. The status frame now carries the turret's angles, and the host
// uses them to cancel the camera's own motion from what it sees; an angle
// reported five times a second would be up to 200 ms stale, which is worse
// than the model it replaces. A 16-byte frame at 50 Hz is 800 B/s against a
// 500 kbaud link, so the cost is nothing.
static const uint32_t STATUS_INTERVAL_MS = 20;
static const uint32_t CONTROL_INTERVAL_MS = 10;  // 100 Hz servo update

// MG90S at 4.8 V manages 60 degrees in 0.1 s. Commanding faster than that
// achieves nothing except current draw.
static const float MAX_RATE_DEG_PER_S = 600.0f;

// Servo::write() takes whole degrees, so commanding through it quantises every
// position to one degree. On this rig one degree is about 32 pixels of frame,
// and the turret steps between them visibly instead of tracking smoothly.
// writeMicroseconds() carries the fractional angle through to the pulse, which
// over 500-2400 us across 180 degrees is roughly 10.6 us per degree -- finer
// than the servo's own resolution, which is where the limit belongs.
static const int PULSE_MIN_US = 500;
static const int PULSE_MAX_US = 2400;
static const float SERVO_RANGE_DEG = 180.0f;

static const float PAN_MIN_DEG = 0.0f;
static const float PAN_MAX_DEG = 180.0f;
// The camera mount fouls the base below 20 degrees; see docs/hardware.md.
static const float TILT_MIN_DEG = 20.0f;
static const float TILT_MAX_DEG = 160.0f;

static const float HOME_PAN_DEG = 90.0f;
static const float HOME_TILT_DEG = 90.0f;

// ---------------------------------------------------------------------- state
Servo servoPan;
Servo servoTilt;
FrameDecoder decoder;

static float targetPan = HOME_PAN_DEG;
static float targetTilt = HOME_TILT_DEG;
static float currentPan = HOME_PAN_DEG;
static float currentTilt = HOME_TILT_DEG;

static bool effectorOn = false;
static bool servosAttached = false;
static bool failsafeActive = true;

static uint32_t lastFrameMs = 0;
static uint32_t lastStatusMs = 0;
static uint32_t lastControlMs = 0;

static uint8_t lastSeq = 0;
static bool haveSeq = false;
static uint16_t droppedFrames = 0;
static uint8_t statusSeq = 0;

static float clampf(float value, float low, float high) {
  if (value < low) return low;
  if (value > high) return high;
  return value;
}

static void attachServos() {
  if (servosAttached) return;
  ESP32PWM::allocateTimer(0);
  ESP32PWM::allocateTimer(1);
  servoPan.setPeriodHertz(50);
  servoTilt.setPeriodHertz(50);
  // 500-2400 us rather than the 1000-2000 default: MG90S servos use the wider
  // range, and clipping it throws away roughly a third of the travel.
  servoPan.attach(PIN_PAN, PULSE_MIN_US, PULSE_MAX_US);
  servoTilt.attach(PIN_TILT, PULSE_MIN_US, PULSE_MAX_US);
  servosAttached = true;
}

static void detachServos() {
  if (!servosAttached) return;
  servoPan.detach();
  servoTilt.detach();
  servosAttached = false;
}

static void enterFailsafe() {
  if (failsafeActive) return;
  failsafeActive = true;
  effectorOn = false;
  digitalWrite(PIN_EFFECTOR, LOW);
  // Detaching stops the PWM: the servos go limp rather than holding a stale
  // position against whatever they are pressed against.
  detachServos();
}

static void leaveFailsafe() {
  if (!failsafeActive) return;
  failsafeActive = false;
  attachServos();
  // Resume from where the servos actually are, not from a stale command.
  targetPan = currentPan;
  targetTilt = currentTilt;
}

static void handleSetAngles(uint8_t seq, const uint8_t *payload, uint8_t length) {
  if (length != sizeof(SetAnglesPayload)) return;

  SetAnglesPayload command;
  memcpy(&command, payload, sizeof(command));

  if (haveSeq) {
    const uint8_t expected = (uint8_t)(lastSeq + 1);
    if (seq != expected) {
      // Sequence gap: frames were lost somewhere. Report it, do not refuse the
      // command -- a fresh position is more useful than a stale one.
      droppedFrames = (uint16_t)(droppedFrames + (uint8_t)(seq - expected));
    }
  }
  lastSeq = seq;
  haveSeq = true;

  targetPan = clampf(command.pan_centideg / 100.0f, PAN_MIN_DEG, PAN_MAX_DEG);
  targetTilt = clampf(command.tilt_centideg / 100.0f, TILT_MIN_DEG, TILT_MAX_DEG);

  leaveFailsafe();
  effectorOn = command.effector != 0;
  digitalWrite(PIN_EFFECTOR, effectorOn ? HIGH : LOW);
}

static void sendStatus() {
  StatusPayload status;
  status.last_seq = lastSeq;
  status.dropped_frames = droppedFrames;
  status.crc_errors = decoder.crcErrors();
  status.effector = effectorOn ? 1 : 0;
  // What the servos are being driven to right now, after this firmware's own
  // slew limiting -- not the last commanded target. The host subtracts this
  // from the apparent target bearing to cancel the camera's own motion, so it
  // must be the angle in effect, not the one being approached.
  status.pan_centideg = (int16_t)(currentPan * 100.0f + (currentPan >= 0 ? 0.5f : -0.5f));
  status.tilt_centideg = (int16_t)(currentTilt * 100.0f + (currentTilt >= 0 ? 0.5f : -0.5f));
  sendFrame(Serial, MSG_STATUS, statusSeq++, (const uint8_t *)&status, sizeof(status));
}

static int angleToMicroseconds(float angleDeg) {
  const float span = (float)(PULSE_MAX_US - PULSE_MIN_US);
  float pulse = PULSE_MIN_US + (angleDeg / SERVO_RANGE_DEG) * span;
  return (int)clampf(pulse + 0.5f, (float)PULSE_MIN_US, (float)PULSE_MAX_US);
}

static void stepServos(float dt) {
  const float maxStep = MAX_RATE_DEG_PER_S * dt;

  float deltaPan = targetPan - currentPan;
  deltaPan = clampf(deltaPan, -maxStep, maxStep);
  currentPan += deltaPan;

  float deltaTilt = targetTilt - currentTilt;
  deltaTilt = clampf(deltaTilt, -maxStep, maxStep);
  currentTilt += deltaTilt;

  if (servosAttached) {
    servoPan.writeMicroseconds(angleToMicroseconds(currentPan));
    servoTilt.writeMicroseconds(angleToMicroseconds(currentTilt));
  }
}

void setup() {
  Serial.begin(BAUD_RATE);

  pinMode(PIN_EFFECTOR, OUTPUT);
  digitalWrite(PIN_EFFECTOR, LOW);

  attachServos();
  servoPan.write((int)HOME_PAN_DEG);
  servoTilt.write((int)HOME_TILT_DEG);

  // Start in failsafe: the turret stays inert until the host proves it is
  // there. Anything else means a power cycle can move the turret on its own.
  failsafeActive = false;
  enterFailsafe();

  lastFrameMs = millis();
  lastControlMs = millis();
}

void loop() {
  const uint32_t now = millis();

  while (Serial.available() > 0) {
    if (decoder.feed((uint8_t)Serial.read())) {
      const uint8_t *body = decoder.body();
      const uint8_t type = body[0];
      const uint8_t seq = body[1];

      if (type == MSG_SET_ANGLES) {
        handleSetAngles(seq, body + 2, (uint8_t)(decoder.bodyLength() - 2));
        lastFrameMs = now;
      } else if (type == MSG_HEARTBEAT) {
        lastSeq = seq;
        haveSeq = true;
        lastFrameMs = now;
        leaveFailsafe();
      }
    }
  }

  if (now - lastFrameMs > FAILSAFE_TIMEOUT_MS) {
    enterFailsafe();
  }

  if (now - lastControlMs >= CONTROL_INTERVAL_MS) {
    stepServos((now - lastControlMs) / 1000.0f);
    lastControlMs = now;
  }

  if (now - lastStatusMs >= STATUS_INTERVAL_MS) {
    sendStatus();
    lastStatusMs = now;
  }
}

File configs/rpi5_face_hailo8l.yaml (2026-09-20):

# Face tracking on the Hailo-8L, with no compilation step.
#
# The UAV configuration needs a .hef built from this project's own weights, and
# building one needs the Hailo Dataflow Compiler, which is x86_64 Linux only and
# behind a Developer Zone account. That puts the accelerator out of reach for
# anyone who just wants to see the system run.
#
# This configuration does not have that problem. `yolov5s_personface` ships with
# the `hailo-all` package, is already compiled for the Hailo-8L, and emits
# on-chip NMS in the same layout the Hailo backend here already decodes. It
# turns the turret into a face tracker, which is a fair demonstration of the
# whole loop -- detect, track, select, point -- at full accelerator speed.
#
# Measured on the reference rig (Pi 5, 4 GB, Debian 13):
#   inference 18.4 ms median, end to end 18.5 ms, 54 fps through this pipeline
#   (the device alone does 64.5 fps; the difference is this project's
#   synchronous wrapper, see docs/benchmarks.md section 5)

detector:
  # Ships with hailo-all. No compilation, no Developer Zone account.
  model: /usr/share/hailo-models/yolov5s_personface_h8l.hef
  backend: hailo
  conf_threshold: 0.40
  iou_threshold: 0.45
  # Order taken from the model's own metadata in
  # /usr/share/hailo-models/yolov5_personface.json, which lists
  # ['unlabeled', 'person', 'face'] with label_offset 1 -- so the HEF's class 0
  # is 'person' and class 1 is 'face'. Read, not assumed.
  labels: [person, face]
  # Track faces, not whole people. A face is a small, well-defined target that
  # moves the way the controller expects; a person box spans most of the frame
  # at close range, and its centre barely moves when they lean.
  classes: [face]

camera:
  source: picamera
  width: 1280
  height: 720
  fps: 30.0
  # MEASURE THIS for your own camera and mode. The value here is for an ov5647
  # (Camera Module v1) at 1280x720, where picamera2 selects the 1920x1080
  # sensor mode and reads out a 1928x1080 crop of the 2592x1944 array. The
  # sensor's full-width FOV is 53.5 degrees, so the effective horizontal FOV is
  #     53.5 * 1928/2592 = 39.8 degrees
  # Taking 53.5 from the datasheet would overstate the loop gain by 34%, and
  # using a Camera Module 3's 66 would overstate it by 66%, which oscillates.
  # `python -c "from picamera2 import Picamera2; ..."` and read ScalerCrop.
  horizontal_fov_deg: 39.8

tracker:
  high_threshold: 0.5
  low_threshold: 0.1
  match_threshold: 0.3
  second_match_threshold: 0.2
  # 15 frames at ~54 fps is under 0.3 s of coasting. Long coasting on a target
  # nobody has seen lets the filter drift and then snap when it re-acquires,
  # which reads as the turret lunging across the room.
  max_age: 15
  min_hits: 3

control:
  # MEASURED on this rig: 18.5 ms end to end, from
  # benchmarks/results/latency_yolov5s-personface-int8-hailo8l.json
  latency_s: 0.019
  feedforward_gain: 0.9
  estimator_window: 5
  home_pan_deg: 90.0
  home_tilt_deg: 90.0
  pan:
    min_deg: 0.0
    max_deg: 180.0
    max_rate_deg_s: 600.0
    deadband_deg: 0.5
    # Set `invert` per axis if your servos are mounted mirrored: the turret
    # will drive away from the target rather than towards it, and no amount of
    # gain tuning fixes that.
    invert: false
    kp: 4.5
    ki: 0.5
    kd: 0.25
  tilt:
    min_deg: 20.0
    max_deg: 160.0
    max_rate_deg_s: 600.0
    deadband_deg: 0.5
    invert: false
    kp: 4.5
    ki: 0.5
    kd: 0.25

link:
  enabled: true
  port: /dev/ttyUSB0
  baudrate: 500000
  heartbeat_interval_s: 0.2

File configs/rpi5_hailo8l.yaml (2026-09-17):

# Raspberry Pi 5 + AI HAT+ (Hailo-8L, 13 TOPS) + MG90S pan/tilt turret.
#
# Every value here is either measured or justified in docs/; the ones worth
# re-measuring on your own build are marked.

detector:
  # Produced by tools/export_onnx.py then tools/compile_hailo.sh.
  model: models/uav_yolov8n_640.hef
  backend: hailo
  # 0.35 rather than the usual 0.25: the tracker's low-score pass (see
  # ByteTracker.low_threshold) recovers weak detections, so the detector itself
  # can afford to be stricter and emit fewer false tracks.
  conf_threshold: 0.35
  iou_threshold: 0.45
  labels: [uav]

camera:
  source: picamera
  width: 1280
  height: 720
  fps: 30.0
  # Raspberry Pi Camera Module 3 (standard, not wide): 66 degrees horizontal.
  # MEASURE THIS if you use a different lens - it sets the pixel-to-angle gain,
  # and an error here shows up as a scale error in the whole control loop.
  horizontal_fov_deg: 66.0

tracker:
  high_threshold: 0.5
  low_threshold: 0.1
  match_threshold: 0.3
  second_match_threshold: 0.2
  # 30 frames at 30 fps: one second of coasting through an occlusion.
  max_age: 30
  min_hits: 3

control:
  # MEASURE THIS with benchmarks/bench_latency.py on your own hardware. It is
  # the single most important number in this file: see docs/benchmarks.md.
  latency_s: 0.045
  feedforward_gain: 0.9
  estimator_window: 5
  home_pan_deg: 90.0
  home_tilt_deg: 90.0
  pan:
    min_deg: 0.0
    max_deg: 180.0
    # MG90S at 4.8 V: 0.1 s per 60 degrees.
    max_rate_deg_s: 600.0
    deadband_deg: 0.5
    kp: 4.5
    ki: 0.5
    kd: 0.25
  tilt:
    # Mechanically restricted: the camera mount fouls the base below 20 degrees.
    min_deg: 20.0
    max_deg: 160.0
    max_rate_deg_s: 600.0
    deadband_deg: 0.5
    kp: 4.5
    ki: 0.5
    kd: 0.25

link:
  enabled: true
  port: /dev/ttyUSB0
  baudrate: 500000
  heartbeat_interval_s: 0.2

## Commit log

2026-09-17 Real-time UAV detection and pan/tilt tracking on a Hailo-8L NPU
    Rebuilds this project around vision-based drone tracking on a Raspberry Pi 5
    with the AI HAT+ (Hailo-8L, 13 TOPS), replacing the previous bird-detection
    experiments and the ad-hoc servo scripts.
    Detection
    - YOLOv8n fine-tuned for single-class UAV detection, trained and evaluated on
    the public DUT Anti-UAV benchmark (IEEE T-ITS 2022) under the COCO protocol.
    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
    [base_plate.stl, base_rpi5_tray.stl, bearing_holder.stl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]
2026-09-18 Add pre-commit config and a prediction contact-sheet tool
    pre-commit mirrors the CI lint, format and benchmark-table checks so they fail
    locally rather than in CI. visualise_predictions.py renders ground truth against
    predictions across the object-size range, because aggregate metrics say how well
    a detector does but not what it gets wrong.
2026-09-18 Add pipeline integration tests
    Covers the seams unit tests cannot: the undefined dt on the first frame, the
    controller's integrators being cleared when a target is lost, heartbeats
    continuing while the loop is open, and commands staying inside the configured
    travel limits. A stub detector keeps the whole loop runnable with no weights,
    no NPU and no camera.
2026-09-18 Test the serial link against a fake port
    Covers the safety behaviour rather than the byte pushing: heartbeats keeping the
    firmware's failsafe from tripping while the loop is open, the effector being
    commanded off before the port closes, the port still closing when that write
    fails, and a chatty or corrupt peer being unable to stall or confuse the loop.
    SerialLink takes an injectable port_factory to make this possible; production
    callers are unaffected.
    [serial_link.py]
2026-09-18 Test the overlay drawing
    Pins the two properties that matter: annotating never mutates the frame the
    pipeline still holds, and every branch survives the states it actually meets --
    no target, a coasting track, a track with no history yet.
2026-09-18 Add a tracking benchmark on the DUT Anti-UAV sequences
    Detection accuracy on stills says nothing about whether a lock survives a target
    crossing a rooftop or dimming against cloud. Reports success AUC, precision at
    20 px, per-frame recall and re-acquisition count over the 20 annotated
    sequences, with the caveat that this is detect-and-track without ground-truth
    initialisation and so is not comparable to the dataset's SOT baselines.
    Drops motmetrics from the bench extra, which nothing used, and adds onnx, which
    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
2026-09-18 Teach the fetch script to download the tracking subset
    docs/dataset.md referenced --splits tracking, which did not exist. The tracking
    data ships as two archives (frames and ground truth) rather than one per split,
    so it gets its own path through the script.
2026-09-18 Handle both tracking-annotation layouts
    DUT ships frames under Anti-UAV-Tracking-V0/videoNN/ and annotations under a
    sibling Anti-UAV-Tracking-V0GT/videoNN_gt.txt, not beside the frames. Sequences
    with no findable annotation are now warned about rather than silently dropped.
2026-09-18 Be explicit about what the postprocess row in the latency table means
    An absent row means the host-side decode could not be split out of the backend's
    infer() call, not that it was free. A zero row means the HEF ran NMS on the
    device, which is the point of compiling it that way.
2026-09-18 Resolve the SciPy import at module load, not inside the control loop
    bench_latency.py reported a 1.8 s p99 on the tracking stage against a 0.6 ms
    median: importing scipy.optimize lazily inside match(), paid on whichever frame
    first had both a track and a detection. The median hid it entirely.
    Stage p99 is now 1.0 ms and end-to-end p99 drops from 1959 ms to 164 ms. Also
    caches OnnxDetector.name at construction, since the benchmark scripts read it
    while writing their results file, which happens after close().
2026-09-18 Add a driver that runs the whole benchmark sweep
    One command, correct order, and benchmarks whose inputs are missing are skipped
    with a reason instead of failing the run. Most people will have neither a Hailo
    device nor the tracking subset, and the benchmarks they can run should still
    produce a report.
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2026-09-18 State plainly what the project does not do
    Which numbers are Hailo's published figures rather than mine, that the pointing
    results are simulation and what the servo model leaves out, that the INT8 study
    is a proxy for the Hailo quantiser, and the standing limits: monocular so no
    range, one target at a time, visible light only, servo model unidentified.
2026-09-18 Pin when the greedy association fallback is optimal, and when it is not
    The docstring claimed the greedy fallback and the Hungarian solver simply agree.
    Measured: on IoU-like matrices, where each track has one strong overlap and the
    rest near zero, they agree on 500 of 500. On uniform random costs they disagree
    about one time in nine, by up to a third of the total.
    The claim is now scoped to the shape of problem this tracker actually sees, and
    both halves are tested, so the docstring cannot quietly overstate it again.
2026-09-18 Test the frame sources
    The device-backed sources need a device, but what actually goes wrong can be
    covered: which source a specification resolves to (a bare digit is a device
    index, not a filename), that image-sequence timestamps come from the nominal
    rate so downstream timing is reproducible, and that an unreadable frame or a
    missing Picamera2 fails with something that names the cause.
2026-09-18 Test the CLI and the backend factory
    check is the command people reach for when nothing works, so it has to be right
    about which backend a config resolves to and whether the model is actually
    there; a config typo or a missing file must exit non-zero rather than
    traceback. The factory's error messages matter for the same reason: a wrong
    extension names the alternatives, and a missing HailoRT points at the
    deployment guide rather than surfacing a bare ImportError.
2026-09-18 Enforce the dependency boundary instead of asserting it
    The README claims the Raspberry Pi runtime is NumPy, OpenCV, PyYAML and
    pyserial, with PyTorch, ONNX Runtime and HailoRT behind optional backends. One
    careless module-level import makes that false, and nothing about the failure is
    obvious until pip pulls a 200 MB wheel on a Pi.
    Now checked three ways: no module imports an optional package eagerly, the whole
    library imports in a subprocess with all of them blocked, and the tracker still
    works with SciPy blocked. The blocker uses find_spec -- find_module was removed
    in 3.12, so the first version of this test was silently a no-op, and there is
    now a test guarding against exactly that.
2026-09-18 Translate the Italian Creo part names
    The repository is in English but the CAD sources are not, because they were
    modelled in Italian and renaming a Creo part breaks retrieval by name. So the
    names are translated in place rather than changed.
    prt0001 and prt0002 are Creo's default names, not abbreviations of anything;
    saying so is more useful than leaving a reader to guess. Which STL each part
    exports to was never recorded, so that is not claimed.
2026-09-18 Record the measured results of the full benchmark sweep
    Ten epochs of YOLOv8n on the DUT Anti-UAV training split, then every benchmark
    in benchmarks/ against the untouched 2,200-image test split.
    Detection, COCO protocol, FP32: AP 0.543, AP50 0.886. INT8 costs 2.1% of AP50
    and 14.5% of AP_small -- quantisation barely affects whether the model finds a
    drone and noticeably affects how precisely it boxes it, concentrated on small
    objects. Tracking over 20 sequences and 24,804 frames: 0.593 success AUC, 0.816
    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
2026-09-18 Make the letterbox downscaling kernel selectable
    The ONNX backend scored higher than the PyTorch weights it was exported from,
    which meant either the hand-written decode was wrong or the preprocessing
    differed. Isolating that needed a way to force bilinear, so `letterbox` now
    takes the shrinking kernel by name and `eval_detection.py` exposes it.
    With the kernel matched, this implementation reproduces Ultralytics to within
    0.0001 AP over 2,200 images: the NumPy decode, the coordinate transform and the
    NMS are equivalent to the reference, measured rather than assumed.
    The tests pin two things that are easy to get wrong. At an exact 2:1 downscale
    OpenCV's bilinear filter averages the same 2x2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
2026-09-18 Show the target in the prediction sheet
    Square cells letterboxed 16:9 frames into black bands covering 44% of each
    cell, and a 30-pixel drone in a 1920-wide frame survives the downscale as about
    two pixels, so the sheet showed neither the frame nor the target.
    Cells are now 16:9, and a target too small to read at cell scale gets its region
    magnified into the corner with the source region outlined. Targets already large
    enough to see do not, since an inset over something visible is two more boxes to
    look at and no information.
2026-09-18 Add a provisioning script for the Pi, and fix the install it documents
    `pip install -e .` as written in the deployment guide fails on Raspberry Pi OS
    Bookworm: the system Python is marked externally managed (PEP 668) and pip
    refuses. Anyone following the guide hit a wall at that line.
    tools/provision_pi.sh does the install properly -- a virtualenv created with
    --system-site-packages, because hailo_platform and picamera2 come from apt and
    a plain venv cannot see them -- and then verifies the PCIe link, HailoRT, the
    Python bindings, the package and the camera. It reports every failing check
    rather than exiting on the first, since on a fresh board several usually fail
    together and one at a tim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
2026-09-18 Fix two test bugs that only the target hardware could reveal
    First run of the suite on the Raspberry Pi, and four tests failed. Neither
    failure was a product bug; both were tests asserting something truer of the
    development machine than of the deployment target.
    The resize test asserted that INTER_AREA and INTER_LINEAR are bit-identical at
    an exact 2:1 downscale. They are, on x86. On aarch64 OpenCV's NEON path rounds
    differently and about a third of the pixels come out one intensity level apart.
    One level in 255 cannot change a detection, so the conclusion in
    docs/benchmarks.md stands -- but the word "identical" was never portable, and
    the documentation and the ablation script said it in th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
    [test_control.py]
2026-09-18 Measure latency on the actual Raspberry Pi 5
    Until now every number in this repository came from an x86 desktop, and the
    target hardware was an assumption. It is not any more: a Pi 5 with the AI HAT+,
    hailortcli reporting Device Architecture HAILO8L and firmware 4.23.0, running
    the suite and the latency benchmark over SSH against 80 real frames from the
    test split.
    Pi 5 CPU, FP32 153.6 ms 6.5 fps
    Pi 5 CPU, INT8 75.0 ms 13.3 fps
    x86 desktop FP32 39.8 ms 24.9 fps
    Feeding each measured latency back through the closed-loop simulation turns
    those into the units the project actually cares about: 1.41 degrees of
    steady-state pointing error on the Pi in FP32, 0.99 in I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
2026-09-18 Run on the Hailo-8L, and fix the backend bug that stopped it
    This repository's HailoDetector had never executed. On its first contact with a
    real device it raised AttributeError: FormatOrder.HAILO_NMS does not exist in
    HailoRT 4.23, which split it into HAILO_NMS_BY_CLASS, _BY_SCORE, _ON_CHIP and
    _WITH_BYTE_MASK. The code already looked up the newer names defensively but
    seeded its set with the old one, so it died before reaching that logic. Every
    name is now resolved with getattr.
    With that fixed, measured on the board, through this project's own pipeline:
    Pi 5 CPU FP32 153.6 ms p99 +18.9% 6.5 fps 1.41 deg
    Pi 5 CPU INT8 75.0 ms p99 +27.4% 13.3 fps 0.99 deg
    H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
2026-09-20 Serve the annotated live view over HTTP for a headless Pi
    `run --display` needs a screen on the Pi, which is the wrong shape for a board
    driven over SSH. This runs the same pipeline with the same annotate() overlay
    and serves MJPEG, so the view opens in a browser anywhere on the network.
    The pipeline runs in a worker thread and publishes only the newest frame;
    viewers get whatever is current when they ask. A slow or disconnected browser
    therefore drops frames rather than stalling the control loop, which is the
    trade that matters: the turret must not wait on a viewer.
2026-09-20 Add per-axis reversal, for servos mounted mirrored
    Whether a servo turns the way the optics expect depends on how the horn was
    fitted. On the bench rig both axes drove away from the target instead of
    towards it, which no amount of gain tuning fixes.
    AxisLimits gains an invert flag, applied as a mirror about the centre of travel
    so an axis running 20-160 still lands in 20-160. It is deliberately an output
    mapping only: the controller's internal state, its actuator model and its
    bearing history stay in the optical frame, so no control mathematics changes
    sign with it. A test pins that -- if inversion leaked into the loop the
    reported error would flip and the integrator would wind the wrong wa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
    [gimbal.py, test_control.py]
2026-09-20 Add a live tuning dashboard
    Tuning a tracking loop by editing YAML and restarting costs a minute per
    attempt, and the thing being tuned -- a drone somebody is holding up -- does
    not wait. This serves the annotated stream next to the parameters that matter
    and applies changes to the running pipeline, so the effect of a threshold or a
    gain is visible immediately.
    Edits are queued by the HTTP thread and applied by the worker at a frame
    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
2026-09-20 Track one class from a many-class model, and add a face config that runs on the NPU today
    Two problems, one change.
    A detector trained on many classes hands the tracker everything it sees, and
    the controller points at whichever the selector picks. detector.classes names
    the classes to keep, resolved once at construction against the *detector's*
    label list so a typo fails loudly instead of producing a turret that silently
    never sees anything.
    And the accelerator has been unreachable for anyone without the Hailo Dataflow
    Compiler, because this project's own weights cannot be compiled without it.
    yolov5s_personface ships compiled with hailo-all, emits on-chip NMS in the
    layout the Hailo backe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
    [rpi5_face_hailo8l.yaml]
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2026-09-20 Cancel camera ego-motion from measured angles, not modelled ones
    With the camera bolted to the turret, apparent target motion in the image is
    the sum of the target's motion and the turret's own. The loop already cancelled
    the second term by reconstructing an absolute bearing -- turret angle at
    capture time, plus the target's offset from boresight -- but it took that angle
    from an internal ServoModel whose time constant and delay the README itself
    describes as placeholders. Whatever the model got wrong survived as apparent
    target motion, was fitted as a rate, and was then multiplied by the
    feed-forward gain.
    The firmware knows better: it interpolates towards the commanded angle at
    100 Hz and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
    [esp32_pantilt.ino, gimbal.py, protocol.h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]
2026-09-21 Add gamepad control of the turret
    Aiming the rig, checking the travel limits are where the mechanics actually
    stop, and identifying the servo model -- hold a stick over, watch how long the
    turret takes to arrive, and the time constant the controller currently guesses
    at becomes a measured number. That last one matters now that camera ego-motion
    cancellation depends on the host knowing where the turret is.
    The sticks command a rate rather than a position. A pan/tilt turret has no
    absolute reference a stick could map onto, and the tracking loop already
    commands rates, so the two share a path.
    It keeps sending while the sticks are centred, because the firmware's 500 ms
    failsafe does not disti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

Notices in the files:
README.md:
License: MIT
